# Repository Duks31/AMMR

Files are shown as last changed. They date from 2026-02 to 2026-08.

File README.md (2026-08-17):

# Cika: An Autonomous Mobile Manipulator for Waste Collection and Sorting

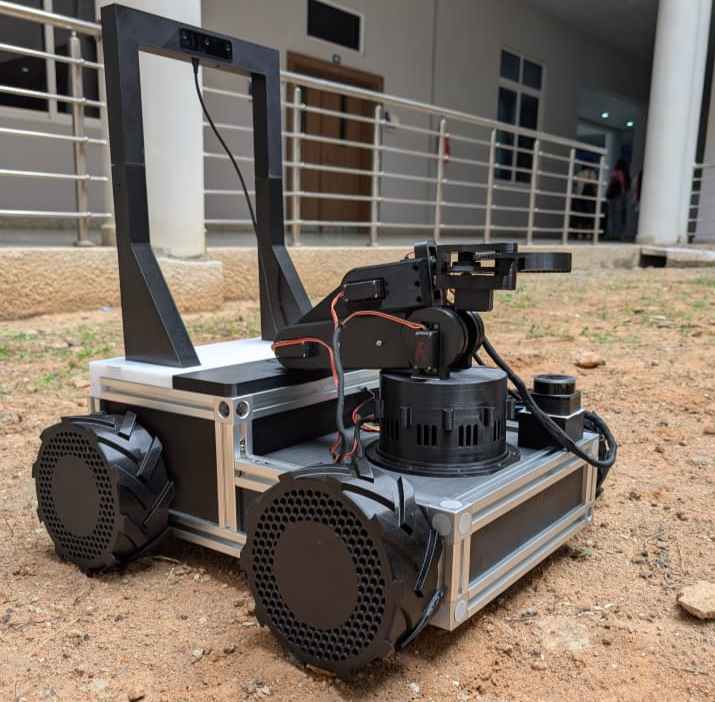
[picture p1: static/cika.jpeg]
cika


## The problem

Waste gets mixed at the point of disposal, plastic and paper end up in the same bin, which kills recycling before it starts. Fixing that manually means more staff hours and more exposure to unsorted waste. Stationary smart bins don't help because they can't go collect litter that never made it into a bin, and most mobile waste robots on record either navigate or sort, not both, and almost none run on renewable power.

Cika is a 4WD skid-steer mobile robot with a 6-DOF arm that finds waste, classifies it as paper or plastic, picks it up, and sorts it.

## System overview

2 subsystems, one control loop:

- **Mobile base**: skid-steer drivetrain, RPLIDAR C1 for 360° scanning, OAK-D Lite for RGB-D and onboard neural inference
- **Manipulator**:  6-DOF serial arm (MG966R servos + a NEMA-17 stepper for base yaw), driven by a PCA9685 PWM controller

Control is split hierarchically: a Raspberry Pi runs ROS2 (Nav2, RTAB-Map, MoveIt2, perception), and talks over serial UART to two ESP32s, one for the drivetrain, one for the arm,  which handle the low-level PWM.

A five-state task manager (`IDLE → SELECTING → NAVIGATING → VERIFYING → PICKING`) ties perception, navigation, and manipulation together: it scores detections by combined detector + classifier confidence, sends the robot to the target, re-confirms it's still there over several frames before committing, then hands off to the arm.

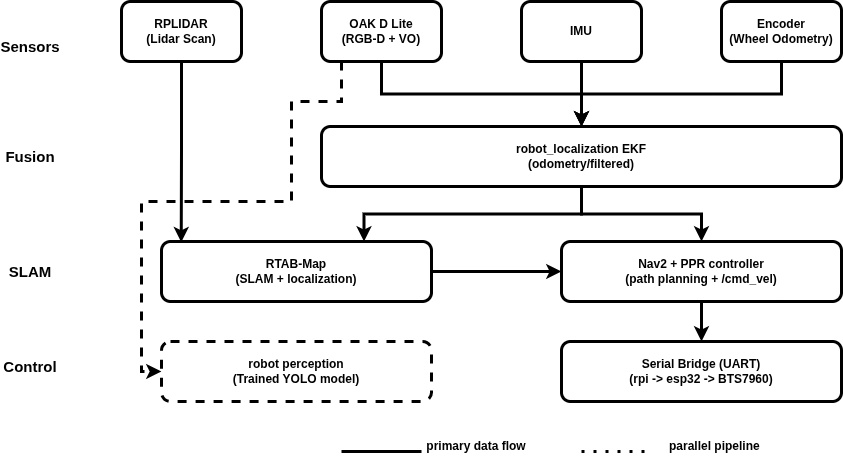
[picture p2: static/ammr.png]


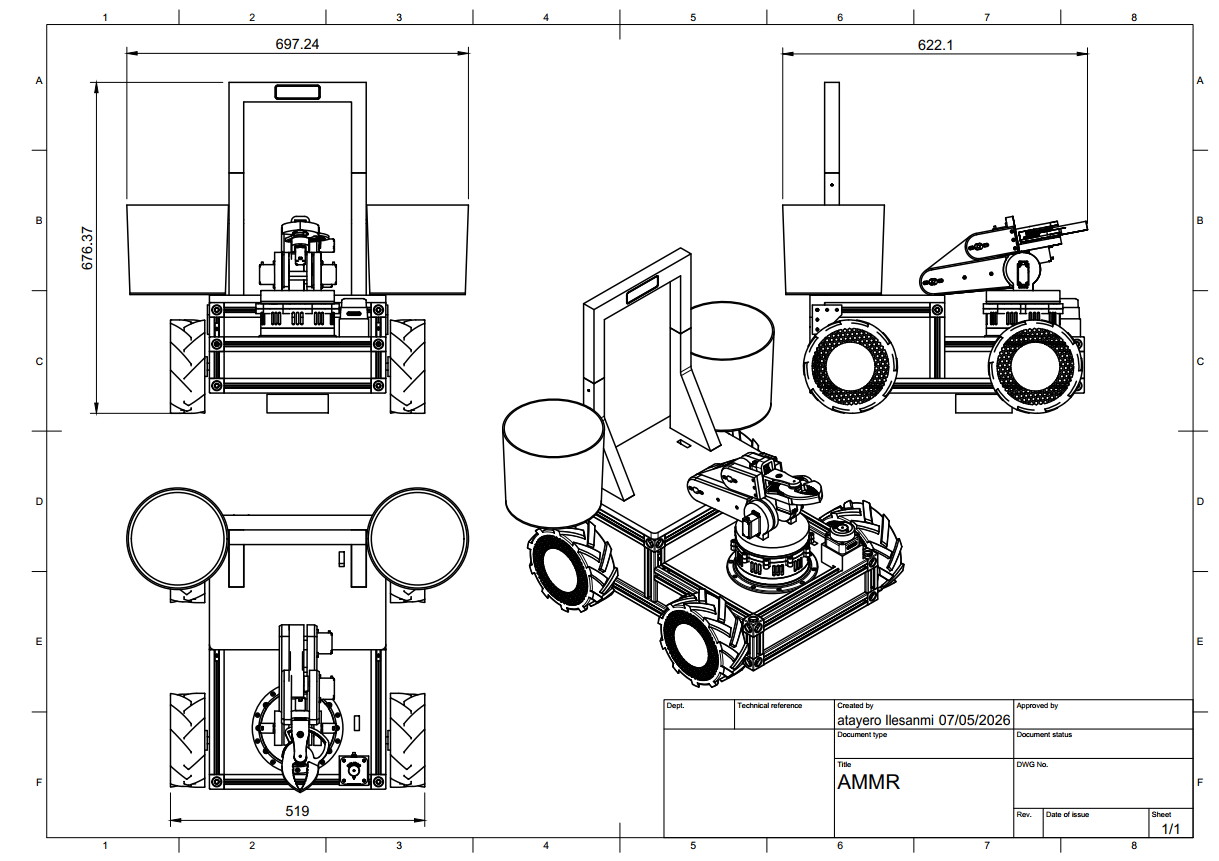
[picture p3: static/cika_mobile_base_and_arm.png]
cika


## Engineering decisions that mattered

**RTAB-Map over SLAM Toolbox.**: I ran both. SLAM Toolbox was the obvious first choice, but RTAB-Map's graph-based approach with appearance-based loop closure held up better on the fused odometry (wheel encoders + IMU + OAK-D Lite visual odometry) once the environment stopped being a clean lab floor. That's the version that shipped.

**27+ sim iterations before the first working build.**: The design phase bounced between Gazebo and Fusion360 then model in Fusion, test the kinematics and drive behavior in Gazebo, find what breaks, go back. That loop is why the final chassis and arm geometry actually match what the drivetrain and manipulator can do, instead of looking right in CAD and failing on hardware.

**Porting the OAK-D Lite pipeline from depthai v2 to v3.**: Not a design choice so much as a forced one, v2 had USB power issues and device crashes that weren't going away. Then I changed to v3 port which meant re-debugging the perception pipeline from scratch, including API breakages that weren't documented anywhere I could find.

**Serial UART instead of micro-ROS for the ESP32s.** micro-ROS was the original plan for the drivetrain and arm controllers. It didn't hold up reliably enough on the Pi ↔ ESP32 link, so I moved both to a plain serial bridge instead, simpler, and it's what's running on the final hardware.

**IMU sign convention (REP-103).** A small thing that cost real debugging time: getting the IMU's axis conventions to actually match ROS's REP-103 standard before the EKF fusion would converge properly.

## What the numbers actually say

I'm including the full metrics table rather than just the highlights, because the gaps are more informative than the wins.

| Metric | Expected | Actual | Deviation |
|---|---|---|---|
| Binary classification accuracy | 100% | 87.4% | 12.6% |
| Object detection accuracy | 75% | 75–81% | within range |
| Navigation success rate | 100% | 58.3% | 41.7% |
| Localization accuracy | 0.05 m | 0.15 m | 66.7% |
| Picking accuracy | 100% | 80% | 20% |
| Wireless power transfer efficiency | 71.4% | 64.3% | 9.9% |
| Positional repeatability | ±0.05 m | ±0.112 m | 55.4% |

The classification and detection numbers (87.4% / 75–81%) are solid for a 2-class YOLOv8 model trained on a TACO subset from a Raspberry Pi-class edge device. The object-detection mAP@0.5 (38.9%) is weaker than the raw accuracy numbers suggest, the confusion matrix shows the model is conservative, preferring to call things "background" over risking a false positive, which is a reasonable failure mode for a robot arm about to grab something.

The navigation numbers are the honest weak point: 58.3% goal success rate against a mean heading error of 16.7° and localization error of 0.15 m. That traces to skid-steer drivetrain slip and asymmetry feeding odometry drift, not a software failure. The Nav2 + RTAB-Map stack did what it was supposed to do with the odometry it was given; the odometry itself wasn't good enough. That's a mechanical problem (wheel bearings, motor bracket tolerances) as much as a perception one.

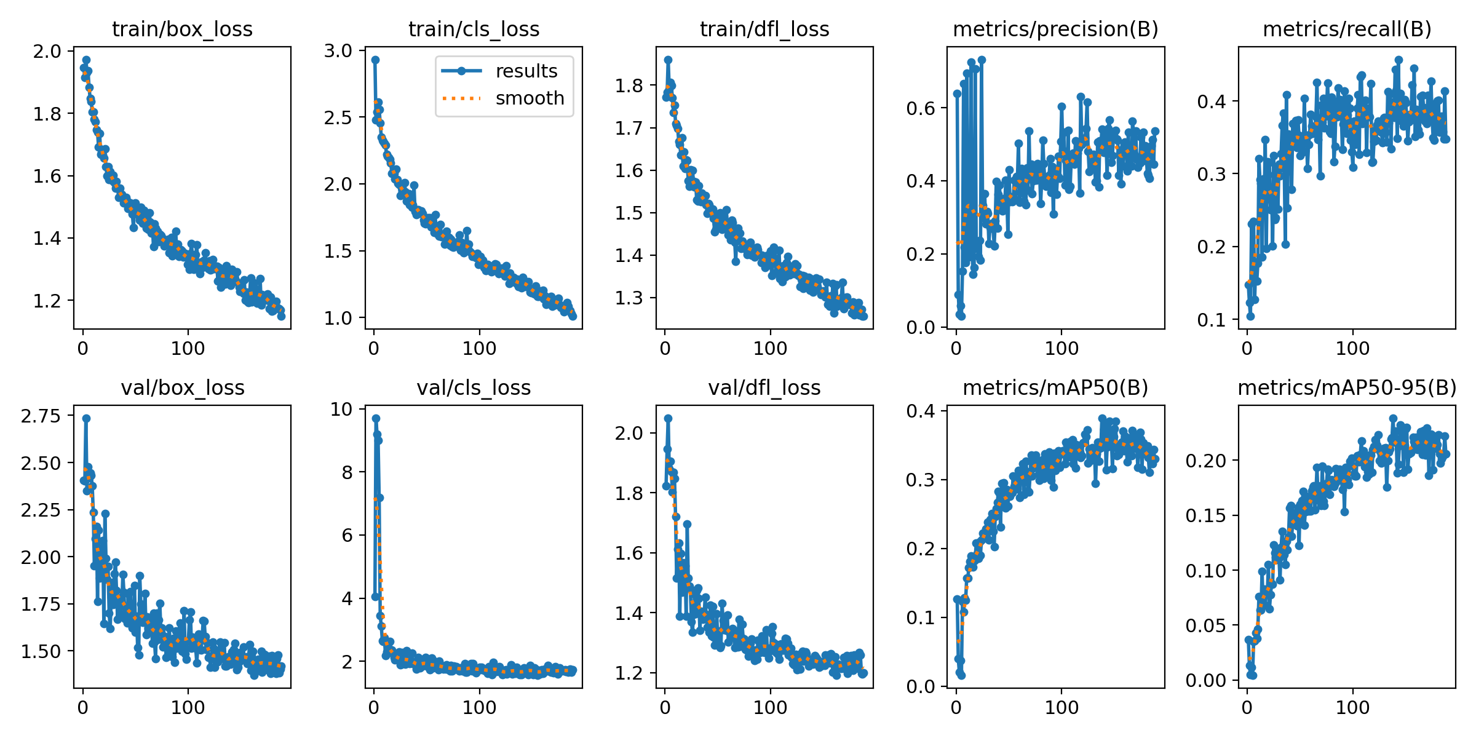
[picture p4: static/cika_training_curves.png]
cika

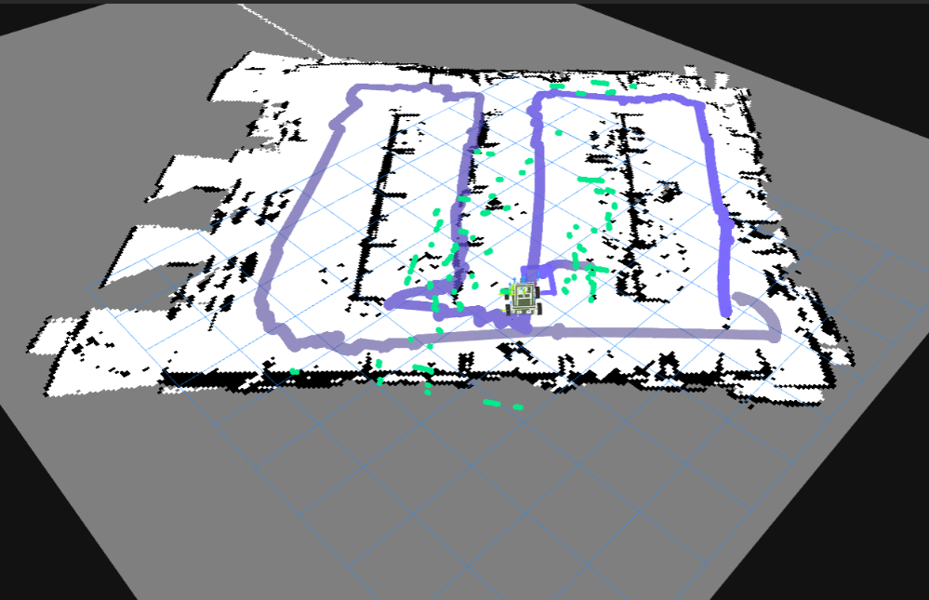
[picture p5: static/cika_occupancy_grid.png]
cika

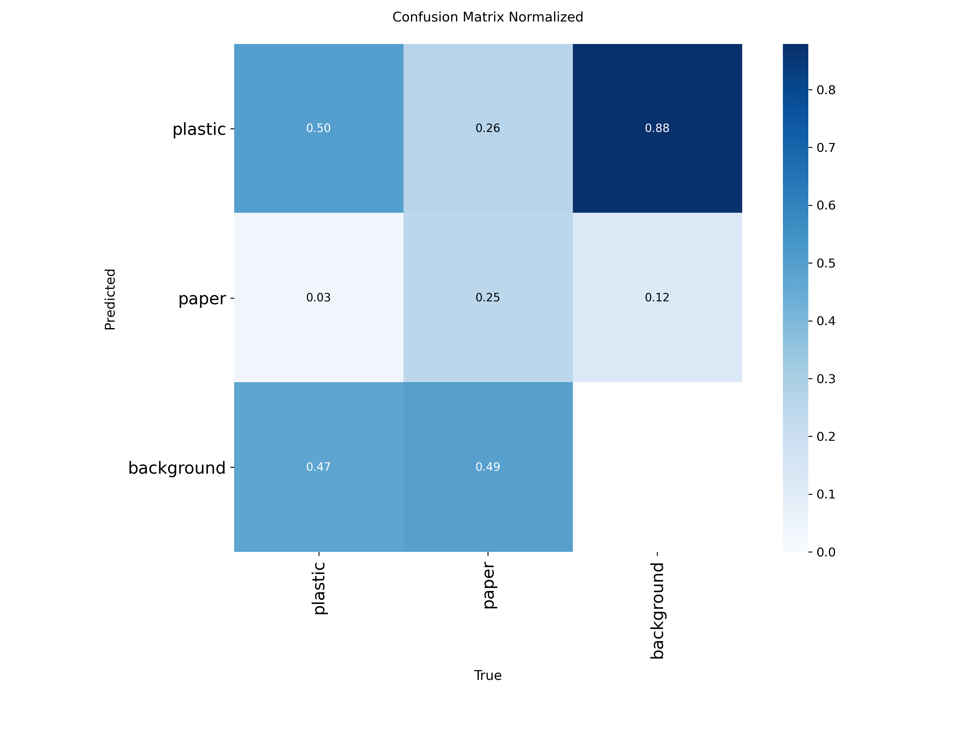
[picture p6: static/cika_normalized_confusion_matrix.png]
cika

## Stack

ROS2 Humble · Nav2 · RTAB-Map · MoveIt2 · YOLOv8 · OAK-D Lite (depthai v3) · RPLIDAR C1 · Extended Kalman Filter sensor fusion · Raspberry Pi 4B · ESP32 · Docker · ONNX / OpenVINO

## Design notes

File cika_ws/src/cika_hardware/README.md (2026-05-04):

# cika_hardware

ros2_control hardware interface plugins for the cika AMR.

## Package contents

```
cika_hardware/
├── include/cika_hardware/
│   └── cika_drive_interface.hpp     # Drive base SystemInterface header
├── src/
│   └── cika_drive_interface.cpp     # Drive base implementation
│   └── drive_esp32_firmware.cpp     # ESP32 firmware
├── cika_hardware_plugins.xml        # pluginlib registration
├── CMakeLists.txt
└── package.xml
```

## What this package does

Replaces the `gz_ros2_control/GazeboSimSystem` plugin with a real hardware
backend when `use_sim:=false`.  The `skid_steer_controller` (diff_drive_controller)
and Nav2 remain completely unchanged — only the bottom layer swaps.

```
Nav2
 └─ skid_steer_controller (diff_drive_controller)
     └─ CikaDriveInterface          ← this package
         ├─ write()  →  publishes /cika/drive/wheel_vel_cmd  →  ESP32  →  BTS7960
         └─ read()   ←  subscribes /cika/odom               ←  ESP32  ←  encoders
```

## Build

```bash
cd ~/code/ws/AMMR/cika_ws
cp -r /path/to/cika_hardware src/
colcon build --packages-select cika_hardware
source install/setup.bash
```

## URDF update

Make sure your launch file passes `use_sim` as a xacro argument:
- Sim:  `use_sim:=true`   → loads GazeboSimSystem (existing behaviour)
- Real: `use_sim:=false`  → loads CikaDriveInterface

## ESP32 firmware
Update these values before flashing:
1. `ENCODER_CPR` — confirm once you have the motor datasheet
2. GPIO pin defines (`L_EN`, `L_RPWM`, `L_LPWM`, `R_EN`, `R_RPWM`, `R_LPWM`)
3. Encoder GPIO pins (`ENCODER_LEFT_A`, `ENCODER_RIGHT_A`)
4. Uncomment the ISR functions and `attachInterrupt()` calls once wired

## Testing (no motor wiring needed yet)

### Step 1 — compile the ROS2 side
```bash
colcon build --packages-select cika_hardware
```

### Step 2 — flash ESP32 and start agent
```bash
# Flash via PlatformIO
pio run --target upload

# Start micro-ROS agent on RPi/laptop
ros2 run micro_ros_agent micro_ros_agent serial --dev /dev/ttyUSB0 -b 115200
```

### Step 3 — verify topics exist
```bash
ros2 node list
# should show: /cika/cika_drive_esp32

ros2 topic list
# should show: /cika/odom  and  /cika/drive/wheel_vel_cmd

ros2 topic echo /cika/odom
```

### Step 4 — start real robot bringup
```bash
ros2 launch cika_bringup cika_bringup.launch.py use_sim:=false
```

### Step 5 — send a test command
```bash
ros2 topic pub /cika/drive/wheel_vel_cmd std_msgs/msg/Float32MultiArray \
  "{data: [1.0, 1.0, 1.0, 1.0]}" --once
```

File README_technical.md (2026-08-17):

# CIKA - Autonomous Mobile Manipulation Robot (AMMR) for Waste Collection and Sorting

## Project Structure 
```
amr_ws/src/
├── cika_description/        # URDF, meshes, ros2_control config
├── cika_bringup/            # Top-level launch files
├── cika_navigation/         # Nav2, SLAM, RTAB-Map
└── cika_manipulation/       # MoveIt2, arm planning, gripper
└── cika_perception/         # Object detection, point cloud processing
└── cika_task_manager/       # High-level task execution, state machine, connections to perception and navigation 
```

## Mapping and Navigation

```bash
# SLAM mode — builds and saves the map database
ros2 launch cika_bringup cika_full_sim.launch.py mode:=slam gui:=false

# Navigation mode — loads saved map and runs Nav2
ros2 launch cika_bringup cika_full_sim.launch.py mode:=navigation gui:=false
```

After a mapping run, the database is saved automatically to
`cika_navigation/maps/cika_map.db`. To switch to navigation mode,
simply relaunch with `mode:=navigation` — no manual copying needed.

> **Warning:** launching `mode:=slam` deletes the existing database on start.
> Back up `cika_warehouse.db` before remapping if you want to keep a good map.
```bash
cp src/cika_navigation/maps/cika_warehouse.db \
   src/cika_navigation/maps/cika_warehouse_backup.db
```

## Perception

```bash
# Simulation — YOLOv8 detector + EfficientNet-B0 classifier, simulated OAK-D Lite
ros2 launch cika_perception perception.launch.py backend:=sim use_sim_time:=true

# Hardware — same pipeline, tuned for Raspberry Pi 4B + physical OAK-D Lite
ros2 launch cika_perception perception.launch.py backend:=hardware use_sim_time:=false
```

The perception pipeline runs two nodes in sequence:

- **detector_node** — runs YOLOv8 on the RGB stream, back-projects detections to 3D using the depth image and camera intrinsics, and publishes on `/cika/waste_detections`
- **classifier_node** — crops each detection bounding box from the RGB frame, runs EfficientNet-B0 to verify the `recyclable` / `non_recyclable` label, and republishes enriched detections on `/cika/waste_detections_classified`

A debug image with bounding boxes and labels is published on `/cika/perception/debug_image` whenever a subscriber is present.

> **Note:** `backend:=sim` and `backend:=hardware` load different parameter configs
> (`perception_sim.yaml` / `perception_hardware.yaml`) — inference rate is 5 Hz in
> sim and 2 Hz on hardware to stay within RPi 4B CPU limits.

## Task Manager

```bash
# Launch task manager (simulation)
ros2 launch cika_task_manager cika_task_manager.launch.py use_sim_time:=true

# Launch task manager (hardware)
ros2 launch cika_task_manager cika_task_manager.launch.py use_sim_time:=false
```

The task manager bridges perception, navigation, and manipulation through a five-state machine:

- **IDLE** — listens to `/cika/waste_detections_classified` and scores candidates by combined detector + classifier confidence
- **SELECTING** — picks the highest-scoring detection with a valid 3D position and triggers navigation
- **NAVIGATING** — sends a `NavigateToPose` goal to Nav2, stopping `approach_distance` (0.4 m) short of the object; retries once on failure before returning to IDLE
- **VERIFYING** — confirms the target is still visible over 5 consecutive detection frames (~3 seconds) before committing to a pick
- **PICKING** — sends a `PickAndDispose` action goal to `cika_manipulator`

## Visualization (Foxglove Studio)

Foxglove Studio is installed system-wide via apt and launched standalone — no ROS2 launch file is needed.

```bash
# Launch Foxglove Studio
foxglove-studio
```

Once open, connect to your running ROS2 stack via the **Foxglove WebSocket** bridge:

```bash
# Start the bridge (run this alongside your other nodes)
ros2 launch foxglove_bridge foxglove_bridge_launch.xml
```

Then in Foxglove Studio, select **Open Connection → Foxglove WebSocket** and enter:
ws://<_ip_address_>:8765

## Physical Robot 

``` bash
# Teleop only (default)
ros2 launch cika_bringup cika_real.launch.py nav:=false

# Compute launch
ros2 launch cika_bringup cika_compute.launch.py 

# SLAM — build a map
ros2 launch cika_navigation cika_nav.launch.py mode:=slam use_sim_time:=false

# Navigation — autonomous with saved map
ros2 launch cika_navigation cika_nav.launch.py mode:=navigation use_sim_time:=false
```

# Cika Hardware Arm — How to Run

## 1. Upload Firmware to ESP32
- Open `cika_arm_esp32.ino` in Arduino IDE
- Board: `ESP32 Dev Module` | Port: `/dev/ttyUSB1`
- Click Upload, then press EN/RESET on ESP32

## 2. Give Port Permission
```bash
sudo chmod a+rw /dev/ttyUSB1
```

## 3. Build
```bash
cd ~/AMMR/cika_ws
colcon build --packages-select cika_hardware_arm
source install/setup.bash
```

## 4. Launch
```bash
ros2 launch cika_bringup cika_real_arm.launch.py
```
```bash
pip install sudo apt install xvfb
xvfb-run -a ros2 launch cika_manipulator moveit.launch.pi.py

```bash
ros2 run cika_manipulator paper_client 
```

## 5. Verify
```bash
ros2 control list_controllers
```
Expected:
```
joint_state_broadcaster   active
arm_controller            active
```

## 6. Monitor ESP32 (optional)
```bash
screen /dev/ttyUSB1 115200
# Close with: Ctrl+A then K → y
```

---

## If Something Goes Wrong
| Problem | Fix |
|---|---|
| Port busy | Close Arduino Serial Monitor or screen |
| Controllers fail | Unplug and replug ESP32, relaunch |
| Wrong port | Change `ttyUSB1` to `ttyUSB0` in `cika_hardware_arm.cpp` and rebuild |

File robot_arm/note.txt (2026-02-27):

2/23/2026 (Kenne)
-created robot_arm_description package
-added launch files
-added gripper

2/24/2026 (Chidubem)
-deleted final_description (unwanted file)

2/27/2026
- Added Controller code for the robot arm

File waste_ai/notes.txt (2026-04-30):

-- KAGGLE OUTPUT --

50 epochs completed in 0.571 hours.
Optimizer stripped from /kaggle/working/runs/detect/ammr_vision/taco_3class_run/weights/last.pt, 22.5MB
Optimizer stripped from /kaggle/working/runs/detect/ammr_vision/taco_3class_run/weights/best.pt, 22.5MB

Validating /kaggle/working/runs/detect/ammr_vision/taco_3class_run/weights/best.pt...
Ultralytics 8.4.45 🚀 Python-3.12.12 torch-2.10.0+cu128 CUDA:0 (Tesla T4, 14913MiB)
Model summary (fused): 73 layers, 11,126,745 parameters, 0 gradients, 28.4 GFLOPs
                 Class     Images  Instances      Box(P          R      mAP50  mAP50-95): 100% ━━━━━━━━━━━━ 9/9 1.7it/s 5.3s0.5s
                   all        258        570      0.411      0.324      0.311      0.232
               plastic        221        415      0.519      0.499      0.451      0.317
                 paper         63         85       0.36      0.188      0.191      0.148
                 metal         36         70      0.354      0.286      0.292      0.229
Speed: 0.2ms preprocess, 4.1ms inference, 0.0ms loss, 1.8ms postprocess per image
Results saved to /kaggle/working/runs/detect/ammr_vision/taco_3class_run

DATA AUGUMENTATION
# --- Data Augmentation Parameters ---
    degrees=45.0,           # Rotate images up to 45 degrees (trash lands at weird angles)
    hsv_s=0.3,              # Alter color saturation by 30% (helps with outdoor vs indoor lighting)
    hsv_v=0.3,              # Alter brightness by 30% (simulates shadows from the robot arm)
    flipud=0.5,             # Flip images upside down 50% of the time 
    fliplr=0.5              # Flip images left/right 50% of the time    

EarlyStopping: Training stopped early as no improvement observed in last 50 epochs. Best results observed at epoch 162, best model saved as best.pt.
To update EarlyStopping(patience=50) pass a new patience value, i.e. `patience=300` or use `patience=0` to disable EarlyStopping.

212 epochs completed in 2.370 hours.
Optimizer stripped from /kaggle/working/runs/detect/ammr_vision/taco_production_run/weights/last.pt, 22.5MB
Optimizer stripped from /kaggle/working/runs/detect/ammr_vision/taco_production_run/weights/best.pt, 22.5MB

Validating /kaggle/working/runs/detect/ammr_vision/taco_production_run/weights/best.pt...
Ultralytics 8.4.45 🚀 Python-3.12.12 torch-2.10.0+cu128 CUDA:0 (Tesla T4, 14913MiB)
Model summary (fused): 73 layers, 11,126,745 parameters, 0 gradients, 28.4 GFLOPs
                 Class     Images  Instances      Box(P          R      mAP50  mAP50-95): 56% ━━━━━━╸───── 5/9 1.4it/s 3.2s<3.0s

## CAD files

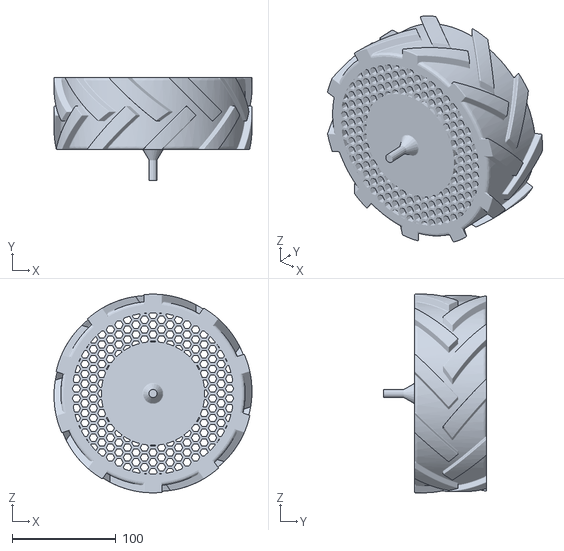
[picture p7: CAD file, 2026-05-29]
cika_ws/src/cika_description/meshes/left_back_wheel_1.stl
191.3 x 100.0 x 191.9

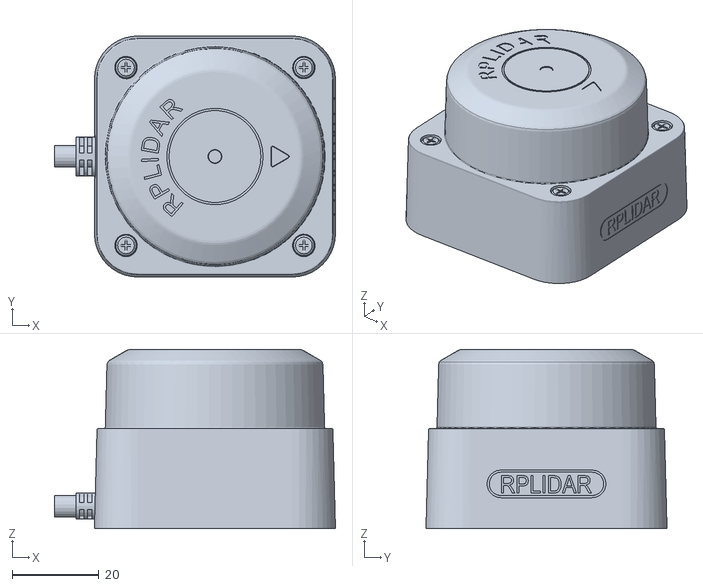
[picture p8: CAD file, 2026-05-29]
cika_ws/src/cika_description/meshes/lidar_1.stl
64.8 x 55.6 x 41.3

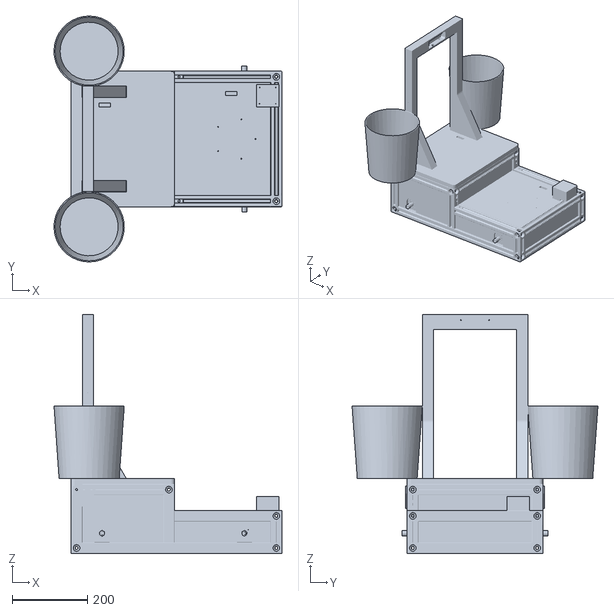
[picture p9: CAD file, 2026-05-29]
cika_ws/src/cika_description/meshes/base_link.stl
605.0 x 652.6 x 635.0

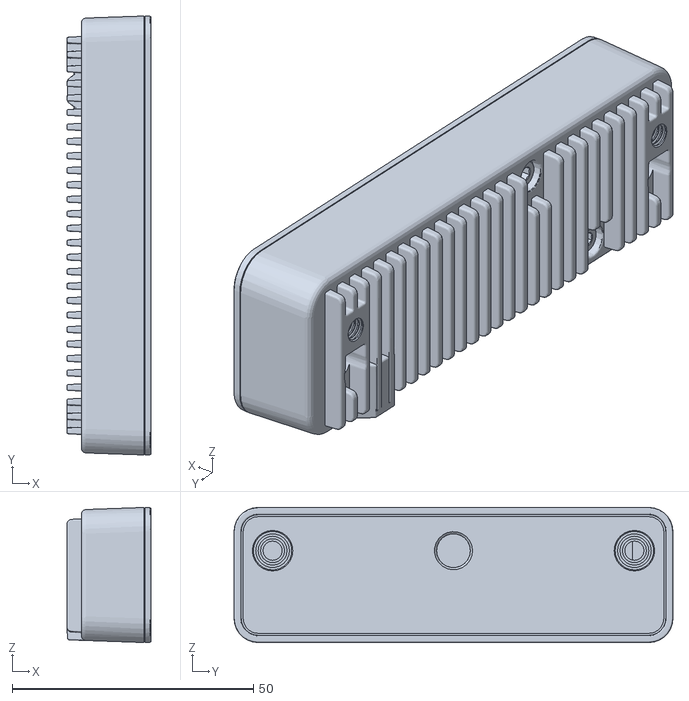
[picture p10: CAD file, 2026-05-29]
cika_ws/src/cika_description/meshes/OAKDcamera_1.stl
17.5 x 91.0 x 28.0

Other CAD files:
cika_ws/src/cika_description/meshes/right_front_wheel_1.stl
cika_ws/src/cika_description/meshes/left_front_wheel_1.stl
cika_ws/src/cika_description/meshes/right_back_wheel_1.stl

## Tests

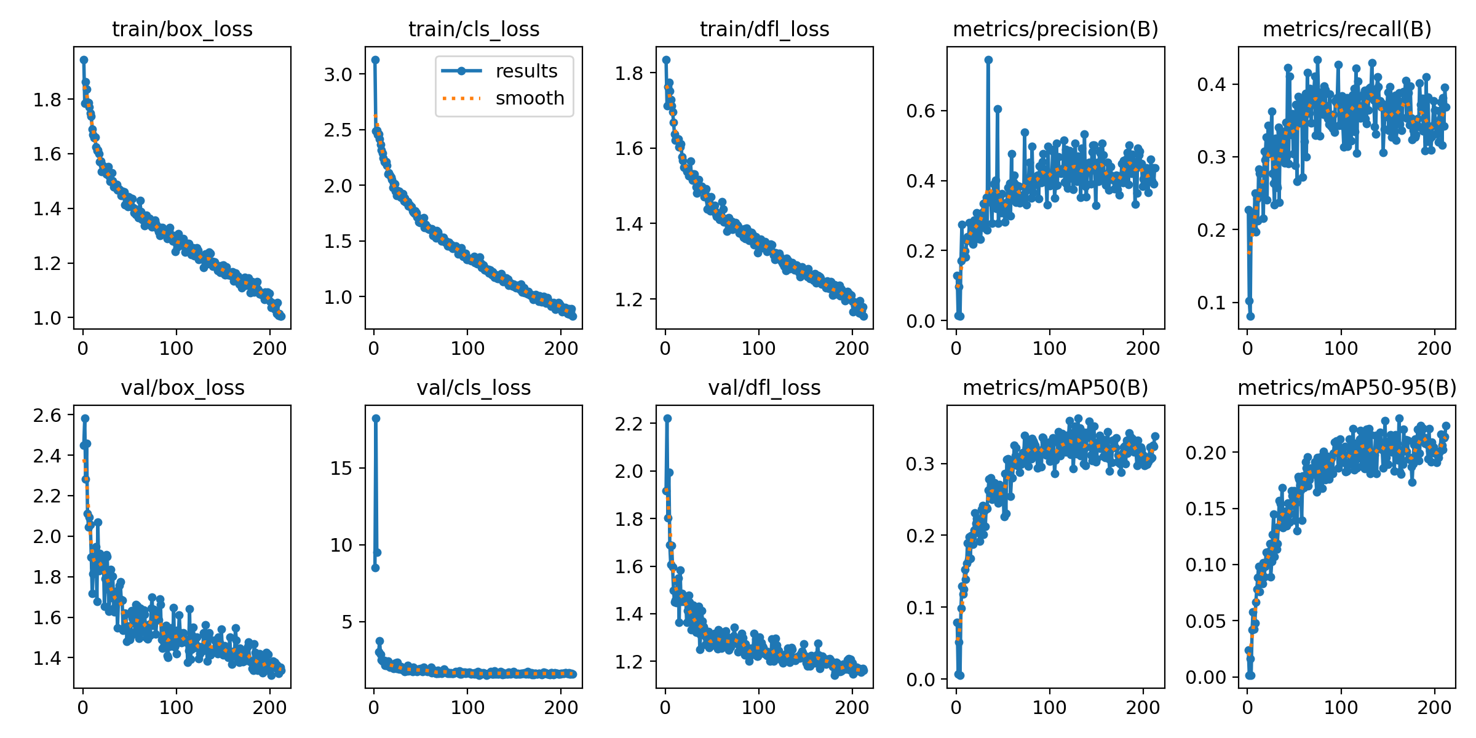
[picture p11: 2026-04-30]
waste_ai/100_epoch_results.png

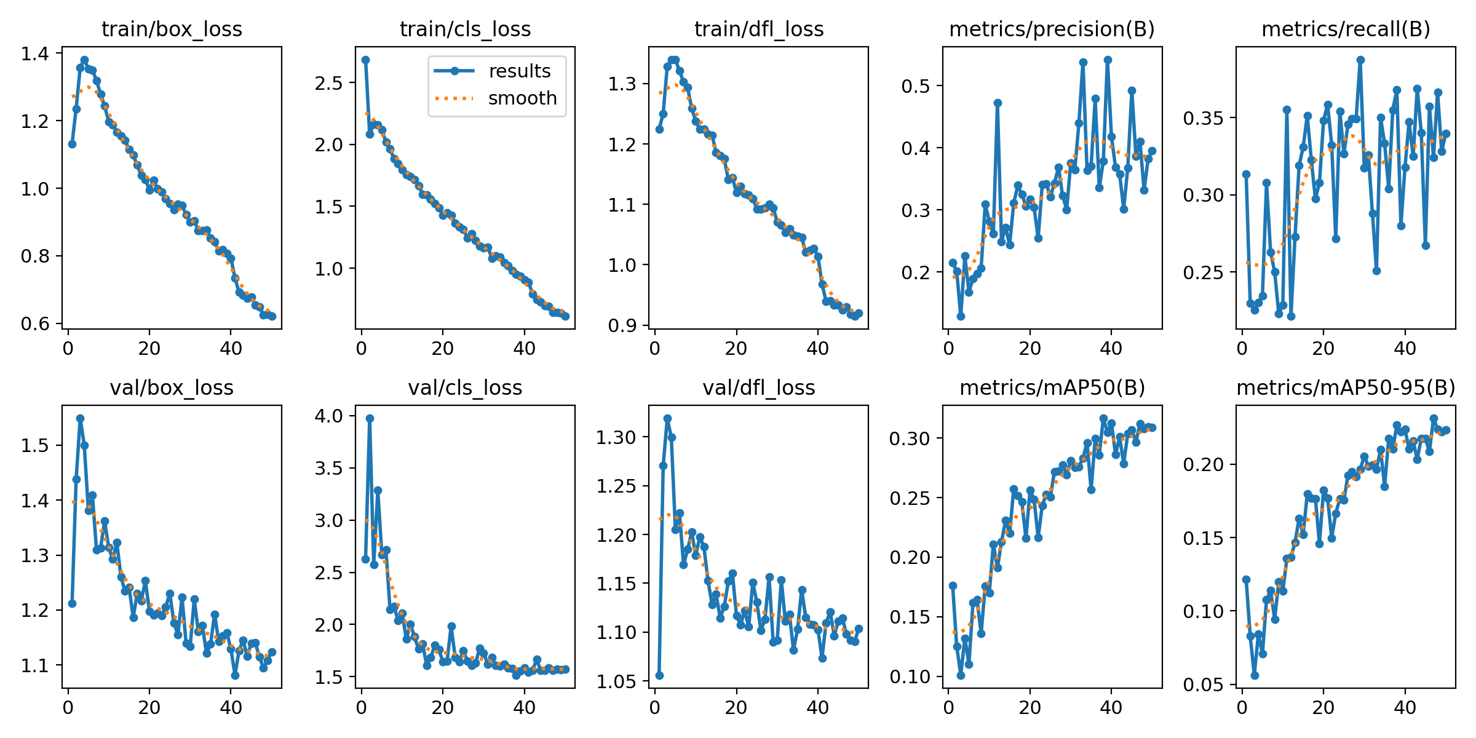
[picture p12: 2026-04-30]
waste_ai/50_epoch_results.png

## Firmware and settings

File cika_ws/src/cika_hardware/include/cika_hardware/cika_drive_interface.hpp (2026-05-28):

#ifndef CIKA_HARDWARE__CIKA_DRIVE_INTERFACE_HPP_
#define CIKA_HARDWARE__CIKA_DRIVE_INTERFACE_HPP_

#include <array>
#include <memory>
#include <string>
#include <vector>

#include "hardware_interface/system_interface.hpp"
#include "hardware_interface/handle.hpp"
#include "hardware_interface/hardware_info.hpp"
#include "hardware_interface/types/hardware_interface_return_values.hpp"
#include "rclcpp/rclcpp.hpp"
#include "rclcpp_lifecycle/state.hpp"
#include "sensor_msgs/msg/imu.hpp"
#include "sensor_msgs/msg/magnetic_field.hpp"
#include "tf2_ros/static_transform_broadcaster.h"

namespace cika_hardware
{

    class CikaDriveInterface : public hardware_interface::SystemInterface
    {
    public:
        CikaDriveInterface() = default;

        // Lifecycle
        hardware_interface::CallbackReturn on_init(
            const hardware_interface::HardwareInfo &info) override;

        std::vector<hardware_interface::StateInterface>
        export_state_interfaces() override;

        std::vector<hardware_interface::CommandInterface>
        export_command_interfaces() override;

        hardware_interface::CallbackReturn on_activate(
            const rclcpp_lifecycle::State &previous_state) override;

        hardware_interface::CallbackReturn on_deactivate(
            const rclcpp_lifecycle::State &previous_state) override;

        // Control loop — called at update_rate (100 Hz per controllers.yaml)
        hardware_interface::return_type read(
            const rclcpp::Time &time,
            const rclcpp::Duration &period) override;

        hardware_interface::return_type write(
            const rclcpp::Time &time,
            const rclcpp::Duration &period) override;

    private:
        // ── Raw Serial Bridge ─────────────────────────────────────────────────────────
        int serial_fd_{-1};
        std::string serial_buffer_;

        // ── ROS2 node handle + publishers ─────────────────────────────────────────────
        // get_node_base_interface() gives us access to the lifecycle node's clock
        rclcpp::Node::SharedPtr node_;
        rclcpp::Publisher<sensor_msgs::msg::Imu>::SharedPtr imu_pub_;
        rclcpp::Publisher<sensor_msgs::msg::MagneticField>::SharedPtr mag_pub_;
        std::shared_ptr<tf2_ros::StaticTransformBroadcaster> tf_static_;

        // ── Drive joint state/command storage ─────────────────────────────────────────
        // hw_states_ layout (8 doubles):
        //   [pos_lf, vel_lf, pos_lb, vel_lb, pos_rf, vel_rf, pos_rb, vel_rb]
        std::array<double, 8> hw_states_{};

        // hw_commands_ layout (4 doubles):
        //   [vel_lf, vel_lb, vel_rf, vel_rb]
        std::array<double, 4> hw_commands_{};

        // ── Dummy storage for arm + gripper joints ────────────────────────────────────
        // (7 joints × 2 = 14 state values, 7 command values).
        // These are exported as zero-valued interfaces so the controller_manager
        // does not crash at startup. They will be replaced by CikaArmInterface.
        //
        // Joint order matches the URDF ros2_control block (indices 4–10):
        //   4: turntable_1_joint
        //   5: lower_arm_1_joint
        //   6: center_arm_1_joint
        //   7: upper_arm_1_joint
        //   8: gripper_mount_1_joint
        //   9: left_gripper_1_joint
        //  10: right_gripper_1_joint
        std::array<double, 14> hw_arm_states_{};  // [pos_j, vel_j] × 7
        std::array<double, 7> hw_arm_commands_{}; // [pos_j] × 7

        // ── Robot geometry ────────────────────────────────────────────────────────────
        double wheel_separation_{0.363};
        double wheel_radius_{0.0885};

        rclcpp::Time last_enc_time_;
    };

} // namespace cika_hardware

#endif // CIKA_HARDWARE__CIKA_DRIVE_INTERFACE_HPP_


// #ifndef CIKA_HARDWARE__CIKA_DRIVE_INTERFACE_HPP_
// #define CIKA_HARDWARE__CIKA_DRIVE_INTERFACE_HPP_

// #include <array>
// #include <memory>
// #include <string>
// #include <vector>

// #include "hardware_interface/system_interface.hpp"
// #include "hardware_interface/handle.hpp"
// #include "hardware_interface/hardware_info.hpp"
// #include "hardware_interface/types/hardware_interface_return_values.hpp"
// #include "rclcpp/rclcpp.hpp"
// #include "rclcpp_lifecycle/state.hpp"
// #include "sensor_msgs/msg/imu.hpp"
// #include "sensor_msgs/msg/magnetic_field.hpp"
// #include "tf2_ros/static_transform_broadcaster.h"

// namespace cika_hardware
// {

// class CikaDriveInterface : public hardware_interface::SystemInterface
// {
// public:
//     CikaDriveInterface() = default;

//     hardware_interface::CallbackReturn on_init(
//         const hardware_interface::HardwareInfo &info) override;

//     std::vector<hardware_interface::StateInterface>
//     export_state_interfaces() override;

//     std::vector<hardware_interface::CommandInterface>
//     export_command_interfaces() override;

//     hardware_interface::CallbackReturn on_activate(
//         const rclcpp_lifecycle::State &previous_state) override;

//     hardware_interface::CallbackReturn on_deactivate(
//         const rclcpp_lifecycle::State &previous_state) override;

//     hardware_interface::return_type read(
//         const rclcpp::Time &time,
//         const rclcpp::Duration &period) override;

//     hardware_interface::return_type write(
//         const rclcpp::Time &time,
//         const rclcpp::Duration &period) override;

// private:
//     // ── TCP Socket ───────────────────────────────────────────────────────────
//     int socket_fd_{-1};
//     std::string serial_buffer_;

//     // ── ROS2 node + publishers ───────────────────────────────────────────────
//     rclcpp::Node::SharedPtr node_;
//     rclcpp::Publisher<sensor_msgs::msg::Imu>::SharedPtr imu_pub_;
//     rclcpp::Publisher<sensor_msgs::msg::MagneticField>::SharedPtr mag_pub_;
//     std::shared_ptr<tf2_ros::StaticTransformBroadcaster> tf_static_;

//     // ── Drive joint state/command storage ────────────────────────────────────
//     // [pos_lf, vel_lf, pos_lb, vel_lb, pos_rf, vel_rf, pos_rb, vel_rb]
//     std::array<double, 8> hw_states_{};
//     // [vel_lf, vel_lb, vel_rf, vel_rb]
//     std::array<double, 4> hw_commands_{};

//     // ── Arm joint storage (dummy — handled by CikaArmInterface) ─────────────
//     std::array<double, 14> hw_arm_states_{};
//     std::array<double, 7>  hw_arm_commands_{};

//     // ── Geometry ─────────────────────────────────────────────────────────────
//     double wheel_separation_{0.363};
//     double wheel_radius_{0.0885};

//     rclcpp::Time last_enc_time_;

//     bool try_reconnect();
//     rclcpp::Time last_reconnect_attempt_;
// };

// } // namespace cika_hardware

// #endif // CIKA_HARDWARE__CIKA_DRIVE_INTERFACE_HPP_

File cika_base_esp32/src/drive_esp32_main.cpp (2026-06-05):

#include <Arduino.h>
#include <Wire.h>
#include <MPU6050.h> // by Electronic Cats - install via Arduino Library Manager

// ── Motor PWM Pins ────────────────────────────────────────────────────────────
#define LEFT_RPWM 27
#define LEFT_LPWM 14
#define LEFT_REN 23
#define LEFT_LEN 26
#define RIGHT_RPWM 32
#define RIGHT_LPWM 33
#define RIGHT_REN 25
#define RIGHT_LEN 2

// ── Encoder Pins ──────────────────────────────────────────────────────────────
#define ENC_LF_A 4
#define ENC_LF_B 5
#define ENC_LB_A 13
#define ENC_LB_B 15
#define ENC_RF_A 18
#define ENC_RF_B 19
#define ENC_RB_A 34
#define ENC_RB_B 16

// ── Kinematics ────────────────────────────────────────────────────────────────
static constexpr float MAX_RAD_S = 1.36f; // Updated for 13rpm ~ 0.12m/s
static constexpr int MIN_PWM = 30;        // TODO: To be Tested
static constexpr float TICKS_TO_RAD = 0.0009584f;

// ── Calibration Offsets ───────────────────────────────────────────────────────
const float accel_x_offset = 0.0103f;
const float accel_y_offset = -0.0217f;
const float accel_z_offset = 0.5211f;
const float gyro_x_offset = -0.0510f;
const float gyro_y_offset = -0.0259f;
const float gyro_z_offset = 0.0080f;

// Mag calibration
const float mag_x_offset = -91.50f;
const float mag_y_offset = 181.00f;
const float mag_z_offset = 307.50f;
const float MAG_SCALE = 0.92f; // µT per LSB at ±1.3Ga

// ── Volatile Encoder Counters ─────────────────────────────────────────────────
volatile long ticks_lf = 0, ticks_lb = 0, ticks_rf = 0, ticks_rb = 0;

// ── Timing ────────────────────────────────────────────────────────────────────
unsigned long last_enc_time = 0; // 50Hz
unsigned long last_imu_time = 0; // 20Hz

// ── IMU ───────────────────────────────────────────────────────────────────────
MPU6050 mpu;

// ── ISRs ─────────────────────────────────────────────────────────────────────
void IRAM_ATTR isr_lf()
{
    if (digitalRead(ENC_LF_B))
        ticks_lf++;
    else
        ticks_lf--;
}
void IRAM_ATTR isr_lb()
{
    if (digitalRead(ENC_LB_B))
        ticks_lb++;
    else
        ticks_lb--;
}
void IRAM_ATTR isr_rf()
{
    if (digitalRead(ENC_RF_B))
        ticks_rf--;
    else
        ticks_rf++;
}
void IRAM_ATTR isr_rb()
{
    if (digitalRead(ENC_RB_B))
        ticks_rb--;
    else
        ticks_rb++;
}

// ── Motor Helpers ─────────────────────────────────────────────────────────────
static void drive(int pwm_l, bool fwd_l, int pwm_r, bool fwd_r)
{
    ledcWrite(LEFT_RPWM, fwd_l ? pwm_l : 0);
    ledcWrite(LEFT_LPWM, fwd_l ? 0 : pwm_l);
    ledcWrite(RIGHT_RPWM, fwd_r ? pwm_r : 0);
    ledcWrite(RIGHT_LPWM, fwd_r ? 0 : pwm_r);
}

static int vel_to_pwm(float vel_rad_s)
{
    int pwm = (int)(fabsf(vel_rad_s) / MAX_RAD_S * 255.0f);
    pwm = constrain(pwm, 0, 255);
    if (pwm > 0 && pwm < MIN_PWM)
        pwm = MIN_PWM;
    return pwm;
}

void enableMPUBypass()
{
    // Write 0x02 to register 0x37 to enable I2C bypass
    Wire.beginTransmission(0x68);
    Wire.write(0x37);
    Wire.write(0x02);
    Wire.endTransmission();
}

bool readMag(float &mx, float &my, float &mz)
{
    Wire.beginTransmission(0x2C); // QMC5883P Address
    Wire.write(0x01);             // Start reading at X LSB
    Wire.endTransmission(false);
    Wire.requestFrom((uint16_t)0x2C, (uint8_t)6);

    if (Wire.available() < 6)
        return false;

    // QMC5883P byte order is X_LSB, X_MSB, Y_LSB, Y_MSB, Z_LSB, Z_MSB
    uint8_t x_lsb = Wire.read();
    uint8_t x_msb = Wire.read();
    uint8_t y_lsb = Wire.read();
    uint8_t y_msb = Wire.read();
    uint8_t z_lsb = Wire.read();
    uint8_t z_msb = Wire.read();

    int16_t rx = (x_msb << 8) | x_lsb;
    int16_t ry = (y_msb << 8) | y_lsb;
    int16_t rz = (z_msb << 8) | z_lsb;

    // Subtract raw offset FIRST, then scale to micro-Teslas (µT)
    mx = (rx - mag_x_offset) * MAG_SCALE;
    my = (ry - mag_y_offset) * MAG_SCALE;
    mz = (rz - mag_z_offset) * MAG_SCALE;

    return true;
}

// ── Setup ─────────────────────────────────────────────────────────────────────
void setup()
{
    Serial.begin(460800);

    // Motor EN pins
    pinMode(LEFT_REN, OUTPUT);
    digitalWrite(LEFT_REN, HIGH);
    pinMode(LEFT_LEN, OUTPUT);
    digitalWrite(LEFT_LEN, HIGH);
    pinMode(RIGHT_REN, OUTPUT);
    digitalWrite(RIGHT_REN, HIGH);
    pinMode(RIGHT_LEN, OUTPUT);
    digitalWrite(RIGHT_LEN, HIGH);

    // PWM
    ledcAttach(LEFT_RPWM, 5000, 8);
    ledcAttach(LEFT_LPWM, 5000, 8);
    ledcAttach(RIGHT_RPWM, 5000, 8);
    ledcAttach(RIGHT_LPWM, 5000, 8);
    drive(0, true, 0, true);

    // Encoders
    pinMode(ENC_LF_A, INPUT_PULLUP);
    pinMode(ENC_LF_B, INPUT_PULLUP);
    pinMode(ENC_LB_A, INPUT_PULLUP);
    pinMode(ENC_LB_B, INPUT_PULLUP);
    pinMode(ENC_RF_A, INPUT_PULLUP);
    pinMode(ENC_RF_B, INPUT_PULLUP);
    pinMode(ENC_RB_A, INPUT_PULLUP);
    pinMode(ENC_RB_B, INPUT_PULLUP);

    attachInterrupt(digitalPinToInterrupt(ENC_LF_A), isr_lf, RISING);
    attachInterrupt(digitalPinToInterrupt(ENC_LB_A), isr_lb, RISING);
    attachInterrupt(digitalPinToInterrupt(ENC_RF_A), isr_rf, RISING);
    attachInterrupt(digitalPinToInterrupt(ENC_RB_A), isr_rb, RISING);

    // IMU — I2C on GPIO 21/22
    Wire.begin(21, 22);
    mpu.initialize();
    enableMPUBypass();
    Wire.beginTransmission(0x2C);
    Wire.write(0x0A); // Control Register 1
    Wire.write(0xCF); // Continuous mode, 200Hz
    Wire.endTransmission();

    if (!mpu.testConnection())
    {
        Serial.println("ERR:MPU6050 not found");
    }
    // MPU6050 library uses raw int16 internally; we read raw and scale manually
    mpu.setFullScaleAccelRange(MPU6050_ACCEL_FS_4); // ±4g  → 8192 LSB/g
    mpu.setFullScaleGyroRange(MPU6050_GYRO_FS_500); // ±500°/s → 65.5 LSB/°/s
}

// ── Main Loop ─────────────────────────────────────────────────────────────────
void loop()
{
    unsigned long now = millis();

    // 1. Read commands from Pi
    if (Serial.available() > 0)
    {
        String incoming = Serial.readStringUntil('\n');
        incoming.trim();
        if (incoming == "<RESET>")
        {
            noInterrupts();
            ticks_lf = ticks_lb = ticks_rf = ticks_rb = 0;
            interrupts();
        }
        else if (incoming.startsWith("<") && incoming.endsWith(">"))
        {
            incoming = incoming.substring(1, incoming.length() - 1);
            float cmds[4];
            int commaIndex = 0;
            for (int i = 0; i < 3; i++)
            {
                commaIndex = incoming.indexOf(',');
                cmds[i] = incoming.substring(0, commaIndex).toFloat();
                incoming = incoming.substring(commaIndex + 1);
            }
            cmds[3] = incoming.toFloat();
            int pwm_l = vel_to_pwm(cmds[0]);
            int pwm_r = vel_to_pwm(cmds[2]);
            drive(pwm_l, cmds[0] >= 0.0f, pwm_r, cmds[2] >= 0.0f);
        }
    }

    if (now - last_enc_time >= 20)
    {
        last_enc_time = now;
        noInterrupts();
        long lf = ticks_lf, lb = ticks_lb, rf = ticks_rf, rb = ticks_rb;
        interrupts();

        Serial.printf("E:%.3f,%.3f,%.3f,%.3f\n",
                      lf * TICKS_TO_RAD, lb * TICKS_TO_RAD,
                      rf * TICKS_TO_RAD, rb * TICKS_TO_RAD);
    }

    unsigned long now2 = millis();
    if (now2 - last_imu_time >= 50)
    {
        last_imu_time = now2;

        int16_t ax_raw, ay_raw, az_raw, gx_raw, gy_raw, gz_raw;
        mpu.getMotion6(&ax_raw, &ay_raw, &az_raw, &gx_raw, &gy_raw, &gz_raw);

        // Scale to SI units and apply calibration offsets
        // ±4g range  → 8192 LSB/g → multiply by 9.80665/8192
        const float A_SCALE = 9.80665f / 8192.0f;
        // ±500°/s range → 65.5 LSB/°/s → multiply by (PI/180)/65.5
        const float G_SCALE = (3.14159265f / 180.0f) / 65.5f;

        float ax = (ax_raw * A_SCALE) - accel_x_offset;
        float ay = (ay_raw * A_SCALE) - accel_y_offset;
        float az = (az_raw * A_SCALE) - accel_z_offset;
        float gx = (gx_raw * G_SCALE) - gyro_x_offset;
        float gy = (gy_raw * G_SCALE) - gyro_y_offset;
        float gz = (gz_raw * G_SCALE) - gyro_z_offset;

        float mx = 0, my = 0, mz = 0;
        bool mag_ok = readMag(mx, my, mz);

        if (mag_ok)
        {
            // Format: I:ax,ay,az,gx,gy,gz,mx,my,mz
            Serial.printf("I:%.4f,%.4f,%.4f,%.4f,%.4f,%.4f,%.4f,%.4f,%.4f\n",
                          ax, ay, az, gx, gy, gz, mx, my, mz);
        }
        else
        {
            // Send without mag so pipeline doesn't stall
            Serial.printf("I:%.4f,%.4f,%.4f,%.4f,%.4f,%.4f,0.0,0.0,0.0\n",
                          ax, ay, az, gx, gy, gz);
        }
    }
}


// #include <Arduino.h>
// #include <Wire.h>
// #include <WiFi.h>
// #include <MPU6050.h>

// // ── WiFi Credentials ─────────────────────────────────────────────────────────
// const char* SSID     = "ncep";
// const char* PASSWORD = "googlepixel";
// const uint16_t TCP_PORT = 8888;

// // ── Motor PWM Pins ────────────────────────────────────────────────────────────
// #define LEFT_RPWM 27
// #define LEFT_LPWM 14
// #define LEFT_REN 23
// #define LEFT_LEN 26
// #define RIGHT_RPWM 32
// #define RIGHT_LPWM 33
// #define RIGHT_REN 25
// #define RIGHT_LEN 2

// // ── Encoder Pins ──────────────────────────────────────────────────────────────
// #define ENC_LF_A 4
// #define ENC_LF_B 5
// #define ENC_LB_A 13
// #define ENC_LB_B 15
// #define ENC_RF_A 18
// #define ENC_RF_B 19
// #define ENC_RB_A 34
// #define ENC_RB_B 16

// // ── Kinematics ────────────────────────────────────────────────────────────────
// static constexpr float MAX_RAD_S    = 1.36f;
// static constexpr int   MIN_PWM      = 30;
// static constexpr float TICKS_TO_RAD = 0.0009584f;

// // ── Calibration Offsets ───────────────────────────────────────────────────────
// const float accel_x_offset =  0.0103f;
// const float accel_y_offset = -0.0217f;
// const float accel_z_offset =  0.5211f;
// const float gyro_x_offset  = -0.0510f;
// const float gyro_y_offset  = -0.0259f;
// const float gyro_z_offset  =  0.0080f;

// const float mag_x_offset =  -91.50f;
// const float mag_y_offset =  181.00f;
// const float mag_z_offset =  307.50f;
// const float MAG_SCALE    =    0.92f;

// // ── State ─────────────────────────────────────────────────────────────────────
// volatile long ticks_lf = 0, ticks_lb = 0, ticks_rf = 0, ticks_rb = 0;
// unsigned long last_enc_time = 0;
// unsigned long last_imu_time = 0;

// WiFiServer server(TCP_PORT);
// WiFiClient client;
// // String tcp_rx_buf;
// char tcp_rx_buf[128]; // Fast static buffer
// int rx_index = 0;

// MPU6050 mpu;

// // ── ISRs ──────────────────────────────────────────────────────────────────────
// void IRAM_ATTR isr_lf() { if (digitalRead(ENC_LF_B)) ticks_lf++; else ticks_lf--; }
// void IRAM_ATTR isr_lb() { if (digitalRead(ENC_LB_B)) ticks_lb++; else ticks_lb--; }
// void IRAM_ATTR isr_rf() { if (digitalRead(ENC_RF_B)) ticks_rf--; else ticks_rf++; }
// void IRAM_ATTR isr_rb() { if (digitalRead(ENC_RB_B)) ticks_rb--; else ticks_rb++; }

// // ── Motor Helpers ─────────────────────────────────────────────────────────────
// static void drive(int pwm_l, bool fwd_l, int pwm_r, bool fwd_r)
// {
//     ledcWrite(LEFT_RPWM,  fwd_l ? pwm_l : 0);
//     ledcWrite(LEFT_LPWM,  fwd_l ? 0 : pwm_l);
//     ledcWrite(RIGHT_RPWM, fwd_r ? pwm_r : 0);
//     ledcWrite(RIGHT_LPWM, fwd_r ? 0 : pwm_r);
// }

// static int vel_to_pwm(float vel_rad_s)
// {
//     int pwm = (int)(fabsf(vel_rad_s) / MAX_RAD_S * 255.0f);
//     pwm = constrain(pwm, 0, 255);
//     if (pwm > 0 && pwm < MIN_PWM) pwm = MIN_PWM;
//     return pwm;
// }

// // ── Mag ───────────────────────────────────────────────────────────────────────
// void enableMPUBypass()
// {
//     Wire.beginTransmission(0x68);
//     Wire.write(0x37);
//     Wire.write(0x02);
//     Wire.endTransmission();
// }

// bool readMag(float &mx, float &my, float &mz)
// {
//     Wire.beginTransmission(0x2C);
//     Wire.write(0x01);
//     Wire.endTransmission(false);
//     Wire.requestFrom((uint16_t)0x2C, (uint8_t)6);
//     if (Wire.available() < 6) return false;

//     uint8_t x_lsb = Wire.read(), x_msb = Wire.read();
//     uint8_t y_lsb = Wire.read(), y_msb = Wire.read();
//     uint8_t z_lsb = Wire.read(), z_msb = Wire.read();

//     mx = ((int16_t)((x_msb << 8) | x_lsb) - mag_x_offset) * MAG_SCALE;
//     my = ((int16_t)((y_msb << 8) | y_lsb) - mag_y_offset) * MAG_SCALE;
//     mz = ((int16_t)((z_msb << 8) | z_lsb) - mag_z_offset) * MAG_SCALE;
//     return true;
// }

// // ── Parse and execute one command line ───────────────────────────────────────
// void handle_command(const char* line)
// {
//     Serial.println(line);   

//     if (strncmp(line, "<RESET>", 7) == 0) {
//         noInterrupts();
//         ticks_lf = ticks_lb = ticks_rf = ticks_rb = 0;
//         interrupts();
//     } 
//     else if (line[0] == '<') {
//         float lf, lb, rf, rb;
//         // sscanf is significantly faster than String.toFloat()
//         if (sscanf(line, "<%f,%f,%f,%f>", &lf, &lb, &rf, &rb) == 4) {
//             drive(vel_to_pwm(lf), lf >= 0.0f,
//                   vel_to_pwm(rf), rf >= 0.0f);
//         }
//     }
// }

// // ── Setup ─────────────────────────────────────────────────────────────────────
// void setup()
// {
//     Serial.begin(115200);

//     // Motors
//     pinMode(LEFT_REN,  OUTPUT); digitalWrite(LEFT_REN,  HIGH);
//     pinMode(LEFT_LEN,  OUTPUT); digitalWrite(LEFT_LEN,  HIGH);
//     pinMode(RIGHT_REN, OUTPUT); digitalWrite(RIGHT_REN, HIGH);
//     pinMode(RIGHT_LEN, OUTPUT); digitalWrite(RIGHT_LEN, HIGH);

//     ledcAttach(LEFT_RPWM,  5000, 8);
//     ledcAttach(LEFT_LPWM,  5000, 8);
//     ledcAttach(RIGHT_RPWM, 5000, 8);
//     ledcAttach(RIGHT_LPWM, 5000, 8);
//     drive(0, true, 0, true);

//     // Encoders
//     pinMode(ENC_LF_A, INPUT_PULLUP); pinMode(ENC_LF_B, INPUT_PULLUP);
//     pinMode(ENC_LB_A, INPUT_PULLUP); pinMode(ENC_LB_B, INPUT_PULLUP);
//     pinMode(ENC_RF_A, INPUT_PULLUP); pinMode(ENC_RF_B, INPUT_PULLUP);
//     pinMode(ENC_RB_A, INPUT_PULLUP); pinMode(ENC_RB_B, INPUT_PULLUP);

//     attachInterrupt(digitalPinToInterrupt(ENC_LF_A), isr_lf, RISING);
//     attachInterrupt(digitalPinToInterrupt(ENC_LB_A), isr_lb, RISING);
//     attachInterrupt(digitalPinToInterrupt(ENC_RF_A), isr_rf, RISING);
//     attachInterrupt(digitalPinToInterrupt(ENC_RB_A), isr_rb, RISING);

//     // IMU
//     Wire.begin(21, 22);
//     mpu.initialize();
//     enableMPUBypass();
//     Wire.beginTransmission(0x2C);
//     Wire.write(0x0A);
//     Wire.write(0xCF);
//     Wire.endTransmission();
//     mpu.setFullScaleAccelRange(MPU6050_ACCEL_FS_4);
//     mpu.setFullScaleGyroRange(MPU6050_GYRO_FS_500);

//     // WiFi
//     Serial.printf("Connecting to %s\n", SSID);
//     WiFi.begin(SSID, PASSWORD);
//     while (WiFi.status() != WL_CONNECTED) {
//         delay(500);
//         Serial.print(".");
//     }
//     Serial.printf("\nConnected! IP: %s\n", WiFi.localIP().toString().c_str());

//     server.begin();
//     server.setNoDelay(true);
//     Serial.printf("TCP server on port %d\n", TCP_PORT);
// }

// // ── Loop ──────────────────────────────────────────────────────────────────────
// void loop()
// {
//     // Accept new client if none connected
//     if (!client || !client.connected()) {
//         client = server.accept();
//         if (client) {
//             Serial.println("Client connected");
//             rx_index = 0; // Reset buffer
//         }
//     }

//     // Read incoming commands efficiently
//     if (client && client.connected() && client.available()) {
//         while (client.available()) {
//             char c = client.read();
//             if (c == '\n') {
//                 tcp_rx_buf[rx_index] = '\0'; // Null-terminate the string
//                 if (rx_index > 0) handle_command(tcp_rx_buf);
//                 rx_index = 0; // Reset for the next packet
//             } 
//             else if (rx_index < sizeof(tcp_rx_buf) - 1) {
//                 // Ignore carriage returns, only add valid chars
//                 if (c != '\r') {
//                     tcp_rx_buf[rx_index++] = c;
//                 }
//             }
//         }
//     }

//     unsigned long now = millis();

//     // Encoder telemetry at 10 Hz
//     if (now - last_enc_time >= 100) {
//         last_enc_time = now;
//         noInterrupts();
//         long lf = ticks_lf, lb = ticks_lb, rf = ticks_rf, rb = ticks_rb;
//         interrupts();

//         if (client && client.connected()) {
//             client.printf("E:%.3f,%.3f,%.3f,%.3f\n",
//                           lf * TICKS_TO_RAD, lb * TICKS_TO_RAD,
//                           rf * TICKS_TO_RAD, rb * TICKS_TO_RAD);
//         }
//     }

//     // IMU telemetry at 5 Hz
//     if (now - last_imu_time >= 50) {
//         last_imu_time = now;

//         int16_t ax_r, ay_r, az_r, gx_r, gy_r, gz_r;
//         mpu.getMotion6(&ax_r, &ay_r, &az_r, &gx_r, &gy_r, &gz_r);

//         const float A_SCALE = 9.80665f / 8192.0f;
//         const float G_SCALE = (3.14159265f / 180.0f) / 65.5f;

//         float ax = (ax_r * A_SCALE) - accel_x_offset;
//         float ay = (ay_r * A_SCALE) - accel_y_offset;
//         float az = (az_r * A_SCALE) - accel_z_offset;
//         float gx = (gx_r * G_SCALE) - gyro_x_offset;
//         float gy = (gy_r * G_SCALE) - gyro_y_offset;
//         float gz = (gz_r * G_SCALE) - gyro_z_offset;

//         float mx = 0, my = 0, mz = 0;
//         bool mag_ok = readMag(mx, my, mz);

//         if (client && client.connected()) {
//             if (mag_ok)
//                 client.printf("I:%.4f,%.4f,%.4f,%.4f,%.4f,%.4f,%.4f,%.4f,%.4f\n",
//                                ax, ay, az, gx, gy, gz, mx, my, mz);
//             else
//                 client.printf("I:%.4f,%.4f,%.4f,%.4f,%.4f,%.4f,0.0,0.0,0.0\n",
//                                ax, ay, az, gx, gy, gz);
//         }
//     }
// }

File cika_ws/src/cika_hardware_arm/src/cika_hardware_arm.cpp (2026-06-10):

// Serial Communication Includes
#include <fcntl.h>    // File controls like O_RDWR
#include <errno.h>    // Error integer and strerror()
#include <unistd.h>   // write(), read(), close()
#include <chrono>
#include <thread>
#include <cstring>
#include <cmath>
#include <algorithm>

#include "cika_hardware_arm/cika_hardware_arm.hpp"
#include "hardware_interface/types/hardware_interface_type_values.hpp"
#include "rclcpp/rclcpp.hpp"

namespace cika_hardware_arm
{
    // ─────────────────────────────────────────────
    // on_init
    // ─────────────────────────────────────────────
    hardware_interface::CallbackReturn CikaHardware::on_init(
        const hardware_interface::HardwareInfo & info)
    {
        if (hardware_interface::SystemInterface::on_init(info) !=
            hardware_interface::CallbackReturn::SUCCESS)
        {
            return hardware_interface::CallbackReturn::ERROR;
        }

        hw_states_position_.assign(info_.joints.size(), 0.0);
        hw_states_velocity_.assign(info_.joints.size(), 0.0);
        hw_commands_.assign(info_.joints.size(), 0.0);

        for (const hardware_interface::ComponentInfo & joint : info_.joints)
        {
            if (joint.command_interfaces.size() != 1 || joint.command_interfaces[0].name != hardware_interface::HW_IF_POSITION)
            {
                RCLCPP_FATAL(rclcpp::get_logger("CikaHardware"), "Joint '%s' missing position command interface.", joint.name.c_str());
                return hardware_interface::CallbackReturn::ERROR;
            }

            if (joint.state_interfaces.size() != 2 || 
                joint.state_interfaces[0].name != hardware_interface::HW_IF_POSITION ||
                joint.state_interfaces[1].name != hardware_interface::HW_IF_VELOCITY)
            {
                RCLCPP_FATAL(rclcpp::get_logger("CikaHardware"), "Joint '%s' missing position/velocity state interfaces.", joint.name.c_str());
                return hardware_interface::CallbackReturn::ERROR;
            }
        }

        return hardware_interface::CallbackReturn::SUCCESS;
    }

    // ─────────────────────────────────────────────
    // on_configure
    // ─────────────────────────────────────────────
    hardware_interface::CallbackReturn CikaHardware::on_configure(
        const rclcpp_lifecycle::State & /*previous_state*/)
    {
        for (uint i = 0; i < hw_states_position_.size(); i++)
        {
            hw_states_position_[i] = 0.0;
            hw_states_velocity_[i] = 0.0;
            hw_commands_[i] = 0.0;
        }

        RCLCPP_INFO(rclcpp::get_logger("CikaHardware"), "Successfully configured!");
        return hardware_interface::CallbackReturn::SUCCESS;
    }

    // ─────────────────────────────────────────────
    // on_activate
    // ─────────────────────────────────────────────
    hardware_interface::CallbackReturn CikaHardware::on_activate(
        const rclcpp_lifecycle::State & /*previous_state*/)
    {
        // std::string port_name = "/dev/ttyUSB0";
        std::string port_name = "/dev/esp32_arm";

        SerialPort = open(port_name.c_str(), O_RDWR);

        // BYPASSING CODE
        if (SerialPort < 0)
        {
            RCLCPP_WARN(rclcpp::get_logger("CikaHardware"), "Arm serial port %s not found — arm disabled.", port_name.c_str());
            return hardware_interface::CallbackReturn::SUCCESS;
        }

        // FORMER CODE (USB Serial)
        // if (SerialPort < 0)
        // {
        //     RCLCPP_ERROR(rclcpp::get_logger("CikaHardware"), "Error opening serial port %s: %s", port_name.c_str(), strerror(errno));
        //     return hardware_interface::CallbackReturn::ERROR;
        // }

        if (tcgetattr(SerialPort, &tty) != 0)
        {
            RCLCPP_ERROR(rclcpp::get_logger("CikaHardware"), "Error getting terminal attributes: %s", strerror(errno));
            close(SerialPort);
            return hardware_interface::CallbackReturn::ERROR;
        }

        // Control Modes
        tty.c_cflag &= ~PARENB;         // No parity
        tty.c_cflag &= ~CSTOPB;         // One stop bit
        tty.c_cflag &= ~CSIZE;          // Clear size bits
        tty.c_cflag |= CS8;             // 8 bits per byte
        tty.c_cflag &= ~CRTSCTS;        // No hardware flow control
        tty.c_cflag |= CREAD | CLOCAL;  // Enable read, ignore modem lines

        // Local Modes
        tty.c_lflag &= ~ICANON;         // Raw mode
        tty.c_lflag &= ~ECHO;           // No echo
        tty.c_lflag &= ~ECHOE;
        tty.c_lflag &= ~ECHONL;
        tty.c_lflag &= ~ISIG;           // No signal chars

        // Input Modes
        tty.c_iflag &= ~(IXON | IXOFF | IXANY); // No software flow control
        tty.c_iflag &= ~(IGNBRK|BRKINT|PARMRK|ISTRIP|INLCR|IGNCR|ICRNL); // Raw input

        // Output Modes
        tty.c_oflag &= ~OPOST;          // Raw output
        tty.c_oflag &= ~ONLCR;          // No newline conversion
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

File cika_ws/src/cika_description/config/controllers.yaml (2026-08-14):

# use_sim_time is set to false for all controllers, as they will be used in real hardware and not in simulation.
# to run in simulation, set use_sim_time to true for all controllers and make sure to launch the controller_manager with the appropriate parameter file that has use_sim_time set to true.

controller_manager:
  ros__parameters:
    use_sim_time: true
    update_rate: 1000 

    joint_state_broadcaster:
      type: joint_state_broadcaster/JointStateBroadcaster

    skid_steer_controller:
      type: diff_drive_controller/DiffDriveController

    arm_controller:
      type: joint_trajectory_controller/JointTrajectoryController

    gripper_controller:
      type: joint_trajectory_controller/JointTrajectoryController

joint_state_broadcaster:
  ros__parameters:
    use_sim_time: true

skid_steer_controller:
  ros__parameters:
    left_wheel_names: ["left_front_wheel_1_joint", "left_back_wheel_1_joint"]
    right_wheel_names: ["right_front_wheel_1_joint", "right_back_wheel_1_joint"]
    wheel_separation: 0.560
    wheel_radius: 0.096
    wheel_separation_multiplier: 1.0
    left_wheel_radius_multiplier: 1.0
    right_wheel_radius_multiplier: 1.0
    publish_rate: 50.0
    odom_frame_id: odom
    base_frame_id: base_footprint
    pose_covariance_diagonal: [0.001, 0.001, 0.001, 0.001, 0.001, 0.01]
    twist_covariance_diagonal: [0.001, 0.001, 0.001, 0.001, 0.001, 0.01]
    open_loop: false
    enable_odom_tf: false #  EKF from robot_localization will publish the odom->base_link transform
    cmd_vel_timeout: 0.5
    use_stamped_vel: false
    use_sim_time: true
    linear:
      x:
        has_velocity_limits: true
        max_velocity: 2.0
        has_acceleration_limits: true
        max_acceleration: 20.0
    angular:
      z:
        has_velocity_limits: true
        max_velocity: 4.0
        has_acceleration_limits: true
        max_acceleration: 25.0

arm_controller:
  ros__parameters:
    joints:
      - turntable_1_joint
      - lower_arm_1_joint
      - center_arm_1_joint
      - upper_arm_1_joint
      - gripper_mount_1_joint
    command_interfaces:
      - position
    state_interfaces:
      - position
    open_loop_control: true
    allow_integration_in_goal_trajectories: true
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

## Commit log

2026-02-19 made robot arm ws and added urdf
    [Base_bottom_1.stl, Base_cylinder_1.stl, Base_servo_mount_1.stl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]
2026-02-23 robot arm description added
    [Base_bottom_1.stl, Base_cylinder_1.stl, Base_servo_mount_1.stl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]
2026-02-24 deleted final_description (unwnated)
    [Base_bottom_1.stl, Base_cylinder_1.stl, Base_servo_mount_1.stl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]
2026-02-24 fixed gripper
    [Base_servo_mount_1.stl, Base_servo_mount__1__1.stl, Bearing_center_bushing__1__1.stl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]
2026-02-26 Latest work before switching to WSL2
    [robot_arm_controllers.yaml]
2026-02-27 controller for robot arm
    [robot_arm_controllers.yaml, robot_arm_description.xacro, ros2_control.xacro]
2026-03-04 Added moveit package and fixed gripper mimic joint urdf
    [joint_limits.yaml, robot_arm.ros2_control.xacro, robot_arm.urdf.xacro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]
2026-03-05 added docker configuration
    [Base_bottom_1.stl, Base_cylinder_1.stl, Base_servo_mount_1.stl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]
2026-03-05 moveit package added
    [joint_limits.yaml, robot_arm.ros2_control.xacro, robot_arm.urdf.xacro]
2026-03-05 Robot description edit
    [robot_arm_description.xacro]
2026-03-05 Edited and optimized packages for moveit2
    [joint_limits.yaml, robot_arm_controllers.yaml, robot_arm_description.xacro]
2026-03-09 fixed joint_limits.yaml
    [joint_limits.yaml]
2026-03-24 added base description and controller
    [base.xacro, base_controller.yaml, base_link.stl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]
2026-03-24 Configured Arm for Pickup
    [Base_bottom_1_collision.stl, Base_cylinder_1_collision.stl, Base_servo_mount_1_collision.stl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]
2026-03-25 Small sequence change in arm operations
2026-03-29 added cika description
    [OAKDcamera_1.stl, arm_bottom_1.stl, center_arm_1.stl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]
2026-03-29 renamed joints for readabiltity
    [cika.xacro]
2026-03-29 removed base_description and amr_bringup
    [base.xacro, base_link.stl, left_back_wheel_1.stl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]
2026-03-30 added oak d lite sensor
    [world.sdf]
2026-03-31 Add lidar sensor (#5)
    * add lidar sensor
    * update note.txt
    [cika.xacro]
2026-03-31 folder arrangement
    [base_controller.yaml]
2026-04-01 ws rename
    [Base_bottom_1.stl, Base_bottom_1_collision.stl, Base_cylinder_1.stl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]
2026-04-03 Navigation (#6)
    * add rtabmap sensor
    * rtabmap update
    * working gazebo sim and controller
    * rtabmap slam v1
    [cika.xacro, test_world.sdf, warehouse_world.sdf]
2026-04-07 Navigation (#7)
    * Timing issues
    * correct config for rtabmap
    * add navigation
    * add maping
    * add nav
    * add nav2
    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
    [cika.xacro, controllers.yaml, warehouse_world.sdf]
2026-04-08 Navigation (#8)
    * update nav readme instruction
    * finalize nav
    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
2026-04-17 Task manager (#10)
    * add task manager
    * added task manager node :state machine
    [warehouse_world.sdf]
2026-04-17 clean up
    [Base_bottom_1.stl, Base_bottom_1_collision.stl, Base_cylinder_1.stl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]
2026-04-18 Perception (#13)
    * add package
    * add perception
    * update model and yaml file
    [perception_hardware.yaml]
2026-04-18 Navigation (#17)
    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
2026-04-27 changed ROD DOMAIN ID
2026-04-27 Cika manipulator (#20)
    * initial config moveit
    * configured gazebo.launch.py
    * fixed moveit errors for testing
    * Fixed moveit bug
    ---------
    [cika.ros2_control.xacro, cika.urdf.xacro, cika.xacro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]
2026-04-27 changed to onnx for inferencing waste ai model
    [perception_hardware.yaml]
2026-04-29 remove src volume mount
2026-04-29 feat: add depthai camera_node for arm64 Pi deployment
2026-04-29 fix: set executable bit on camera_node.py
2026-04-29 fix: add camera node to perception cmake
2026-04-29 mount volume
2026-04-30 fix: camera_node
2026-04-30 fix: camera node
2026-04-30 fix: updare camera node to fit v3
2026-04-30 fix: camera_node
2026-04-30 rewrote the entire percepion and change yolo model
    [perception_hardware.yaml]
2026-04-30 added camera yaml
2026-04-30 changed camera yaml and node
2026-04-30 added stereo to camera yaml
2026-04-30 added nn type for camera
2026-04-30 added camera frame
2026-05-04 Micro ros (#21)
    * micro ros init
    * added base drive interface and base esp32 firmware
    * add readme
    * add hardware code
    [cika.xacro, controllers_real.yaml]
2026-05-04 changed pin
2026-05-05 update signs
    [controllers.yaml, controllers_real.yaml]
2026-05-05 fix: change base link
    [cika.xacro]
2026-05-07 added imu data for ekf
2026-05-07 update on the pwm and speed, linear and angular
    [controllers_real.yaml]
2026-05-08 added lidar node and oak node working for physical
2026-05-11 fix: serial bridge fight
    [cika_drive_interface.cpp, cika_drive_interface.hpp, drive_esp32_main.cpp]
2026-05-11 comment out the imu data
2026-05-12 fix: use mag: false
    [controllers_real.yaml]
2026-05-19 fix -ve wheel spin
    [cika_drive_interface.cpp]
2026-05-19 fix add -ve to wheels for viz
    [cika_drive_interface.cpp]
2026-05-19 fix int to float for ekf yaml
    [ekf_real.yaml]
2026-05-20 update on imu and enc freq
2026-05-25 Cika hardware arm (#22)
    * configured moveit for new branch
    * created hardware interface package for arm components
    * configured initial hardware interface for arm
    * Finished hardware interface for arm. Instrunctions in README.md on how to run
    * Added gripper controller for hardware interface
    * fixed servo value matching in hardware interface
    * Adjusted task client to fit inference node
    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
    [cika.xacro, controllers_real.yaml]
2026-05-25 updated nav rtab map db
    [controllers_real.yaml]
2026-05-26 test fix
    [controllers_real.yaml]
2026-05-27 added base footprint
    [cika.xacro, controllers_real.yaml]
2026-05-27 updated for lidar slam
2026-05-27 updates delay motor =
2026-05-28 changed from serial to wifi on motor esp
2026-05-28 by passing arm
2026-05-28 made code faster for esp32 wifi
2026-05-28 changed publish rate of skid steer for controller
    [controllers_real.yaml]
2026-05-29 edited cika final urdf for the xacro file
    [OAKDcamera_1.stl, arm_bottom_1.stl, base_link.stl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]
2026-05-30 adding visual odometry to the ekf
    [cika.xacro]
2026-05-30 flipped lidar 180 degrees
    [cika.xacro]
2026-05-30 update yaml
    [controllers_real.yaml]
2026-05-31 changed materials for the urdf
    [cika.xacro]
2026-06-01 omo mehn
    [cika.xacro, controllers_real.yaml]
2026-06-01 fix: inference node to default true
    [ekf_real.yaml]
2026-06-01 tested arm movement without cam
2026-06-01 edited URDF
    [cika.xacro]
2026-06-02 edit for camera test
2026-06-04 changed freq for controller from 100 to 50
    [controllers_real.yaml]
2026-06-08 changed IMU gz to +ve
2026-06-08 fix slam and nav
    [ekf_real.yaml, mapper_params_online_async.yaml]
2026-06-08 change polugon and footprint
2026-06-08 edit laser filter
2026-06-10 final push for arm
2026-06-10 changed port for raspberry pi to esp32 for arm
2026-06-11 fixed lower arm angle
2026-06-11 test for lower arm
2026-06-11 test for arm--1
2026-06-11 updated arm file
2026-06-11 test for arm--2
2026-06-11 test for arm--3
2026-06-11 test for arm--4
2026-08-14 working sim, fixed the gravitropic right gripper
    [cika.xacro, controllers.yaml]
2026-08-14 reconfigured the sim slam workflow
    [controllers.yaml]
